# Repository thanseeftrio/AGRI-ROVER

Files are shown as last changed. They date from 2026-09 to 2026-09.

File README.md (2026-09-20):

# Agri Rover 🌾🤖 - Autonomous Agricultural Monitoring Control Center & 3D Engineering Platform

An end-to-end intelligent agricultural field rover and precision monitoring system designed for 1-acre crops (Arecanut, Orchard, and High-Clearance Row Crops).

---

## 🌟 Key Features

1. **Autonomous Crop & Plant Monitoring Dashboard**:
   - Live 1-Acre GPS Matrix Grid (150 plants tracked).
   - Real-time AI Plant Health Diagnostics (Leaf Blight, Water Stress, Frond Health).
   - Live Telemetry & Mission Control with ESP32/RPi bridge interface.
   - Farm Summary Reports and Agro-Advisory Action Plans.

2. **Interactive 3D WebGL Rover Visualizer**:
   - High-Clearance Strut Architecture with top-docked drone.
   - Real-time kinematics: Ground clearance slider (250mm - 550mm), Exploded view (0 - 100%).
   - Autonomous mission demos: Drone flight simulation, motorized soil penetration probe, foliage vision turret sweep.

3. **Production 2D Engineering Drawings & CAD Package**:
   - 4-Sheet Printable AutoCAD Vector Drawings (Front GA, Top Plan, Side Elevation, 3D Isometric).
   - Downloadable DXF manufacturing files and Judges PDF Packages.

---

## 🚀 Live Demo & Deployment

This project is configured for **Vercel**:

- **Web Dashboard**: Main Application (`/`)
- **3D Interactive Rover**: `/agribot_3d_viewer.html` or `/3d`
- **4-Sheet Engineering Drawings**: `/agribot_print_drawings.html` or `/drawings`
- **AutoCAD PDF Package**: `/cad/AgriBot_AutoCAD_2D_Judges_Package.pdf`

---

## 🛠️ Local Development

### 1. Install Dependencies
```bash
npm install
cd client && npm install && cd ..
```

### 2. Run Locally (Full-Stack Dev Server)
```bash
npm run dev
```
- Frontend UI: `http://localhost:5173`
- Backend API Server: `http://localhost:3001`

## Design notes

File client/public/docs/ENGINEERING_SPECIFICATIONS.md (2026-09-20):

# Engineering Specifications & Calculations: AgriBot-X Agricultural Rover

**Project:** Autonomous AI Agricultural Plant Monitoring Rover with Integrated Drone Docking Station  
**Revision:** v1.0  
**Design Philosophy:** "GROUND + AIR + SOIL + PLANT VISION"  

---

## 1. Kinematic & Drivetrain Sizing Analysis

### 1.1 Rover Mass Budget
- Structural Chassis Frame & Bumpers: $11.5\text{ kg}$
- 4WD Wheels, Hubs, Axles & Bearings: $8.2\text{ kg}$
- 4x Planetary Geared BLDC Motors: $6.4\text{ kg}$
- 24V 30Ah LiFePO4 Battery Pack: $6.8\text{ kg}$
- Electronics Enclosure, Compute & Drivers: $3.2\text{ kg}$
- Camera Mast, Pan/Tilt Gimbal & Sensors: $2.4\text{ kg}$
- Motorized Soil Probe Mechanism: $2.1\text{ kg}$
- Drone Docking Platform & Latches: $2.8\text{ kg}$
- Surveillance Quadcopter Drone: $0.9\text{ kg}$
- Auxiliary Wiring, Fasteners & Mounting Plates: $2.2\text{ kg}$
- **Total Unloaded Robot Mass ($M_{base}$):** **$46.5\text{ kg}$**
- **Rated Agricultural Payload ($M_{payload}$):** **$15.0\text{ kg}$**
- **Maximum Gross Operating Mass ($M_{gross}$):** **$61.5\text{ kg}$** ($W = M_{gross} \times g = 61.5 \times 9.81 = 603.3\text{ N}$)

---

### 1.2 Agricultural Terrain Resistance & Tractive Force Calculations
The rover is designed to negotiate loose loam, wet clay, gravel tracks, and crop ridges with an incline of up to $\theta = 20^\circ$ (maximum slope $\theta_{max} = 25^\circ$).

#### A. Rolling Resistance Force ($F_{rr}$)
In tilled or soft agricultural soil, the rolling resistance coefficient ($C_{rr}$) for pneumatic chevron tires is approximately $0.12 - 0.18$. We design for the conservative worst case: $C_{rr} = 0.18$.
$$F_{rr} = C_{rr} \times M_{gross} \times g \times \cos(\theta) = 0.18 \times 603.3 \times \cos(20^\circ) = 0.18 \times 603.3 \times 0.9397 = 102.0\text{ N}$$

#### B. Grade Resistance Force ($F_{grade}$)
On a $20^\circ$ slope ($36.4\%$ grade):
$$F_{grade} = M_{gross} \times g \times \sin(\theta) = 603.3 \times \sin(20^\circ) = 603.3 \times 0.3420 = 206.3\text{ N}$$

#### C. Acceleration Force ($F_{accel}$)
Target acceleration to cruising speed ($v = 1.2\text{ m/s}$) in $t = 1.0\text{ s}$ ($a = 1.2\text{ m/s}^2$):
$$F_{accel} = M_{gross} \times a = 61.5 \times 1.2 = 73.8\text{ N}$$

#### D. Total Required Tractive Force (Drawbar Pull)
$$F_{total} = F_{rr} + F_{grade} + F_{accel} = 102.0\text{ N} + 206.3\text{ N} + 73.8\text{ N} = 382.1\text{ N}$$

With a $1.25$ safety margin for soil compaction and mud resistance:
$$F_{design} = 382.1 \times 1.25 = 477.6\text{ N}$$

---

### 1.3 Motor Torque & Planetary Gearbox Sizing
The drive system utilizes 4 independently driven wheels.
- Number of drive motors: $N = 4$
- Required tractive force per wheel:
  $$F_{wheel} = \frac{F_{design}}{4} = \frac{477.6\text{ N}}{4} = 119.4\text{ N}$$
- Wheel radius ($r_{wheel}$): $\frac{300\text{ mm}}{2} = 0.15\text{ m}$
- Required continuous torque per wheel axle ($T_{axle}$):
  $$T_{axle} = F_{wheel} \times r_{wheel} = 119.4\text{ N} \times 0.15\text{ m} = 17.91\text{ N}\cdot\text{m}$$

#### Motor Sizing Confirmation:
- Selected Motor: Linix/Nidec 24V BLDC Motor with integrated 1:20 Planetary Gearbox.
- Motor nominal speed: $3000\text{ RPM}$
- Gearbox reduction ratio: $i = 20:1$
- Gearbox efficiency: $\eta_{gear} = 88\%$
- Wheel axle output speed: $\frac{3000}{20} = 150\text{ RPM}$
- Maximum linear speed:
  $$v_{max} = \frac{150 \times 2\pi}{60} \times 0.15 = 15.71\text{ rad/s} \times 0.15\text{ m} = 2.36\text{ m/s}\quad (8.5\text{ km/h})$$
  *(Electronically speed-governed to $1.2 - 1.5\text{ m/s}$ during autonomous row navigation)*.
- Motor rated torque at base: $T_{motor} = 1.1\text{ N}\cdot\text{m}$
- Axle output torque available:
  $$T_{available} = T_{motor} \times i \times \eta_{gear} = 1.1 \times 20 \times 0.88 = 19.36\text{ N}\cdot\text{m} > 17.91\text{ N}\cdot\text{m}\quad \text{[PASS]}$$
- Peak stall torque per wheel: $45.0\text{ N}\cdot\text{m}$ (allows unsticking wheels in deep agricultural mud ruts).

---

## 2. Electrical Energy Budget & Battery Runtime Sizing

### 2.1 Power Consumption Breakdown

| Operating Subsystem | Voltage | Operating Current (Avg) | Power (Continuous) | Duty Cycle (%) | Effective Power (W) |
| :--- | :--- | :--- | :--- | :--- | :--- |
| **4WD Motors (Cruising)** | 24.0 V | 4.5 A (Total across 4) | 108.0 W | 65% | 70.2 W |
| **Raspberry Pi 5 (Edge AI)** | 5.0 V | 2.4 A | 12.0 W | 100% | 12.0 W |
| **Hailo-8 AI Inference (26 TOPS)**| 3.3 V | 0.8 A | 2.6 W | 70% | 1.8 W |
| **STM32F4 Motion Microcontroller** | 3.3 V | 0.15 A | 0.5 W | 100% | 0.5 W |
| **Camera Mast Pan/Tilt Gimbal** | 12.0 V | 0.6 A | 7.2 W | 40% | 2.9 W |
| **4K RGB + Depth RealSense D435i** | 5.0 V | 1.4 A | 7.0 W | 80% | 5.6 W |
| **Livox 3D Solid-State LiDAR** | 12.0 V | 1.0 A | 12.0 W | 100% | 12.0 W |
| **u-blox ZED-F9P RTK-GNSS + IMU**| 5.0 V | 0.3 A | 1.5 W | 100% | 1.5 W |
| **4G LTE / LoRaWAN Telemetry** | 5.0 V | 0.4 A | 2.0 W | 30% | 0.6 W |
| **Motorized Soil Probe Actuator** | 24.0 V | 1.5 A | 36.0 W | 15% (At Plant) | 5.4 W |
| **Sensors (Moist/pH/EC/Weather)** | 12.0 V | 0.2 A | 2.4 W | 50% | 1.2 W |
| **Cooling Blowers & Safety LEDs** | 24.0 V | 0.4 A | 9.6 W | 100% | 9.6 W |
| **Drone Fast-Charging Dock** | 24.0 V | 5.0 A (During Dock) | 120.0 W | 12% | 14.4 W |
| **TOTAL WEIGHTED AVERAGE CONSUMPTION** | — | — | — | — | **137.7 W** |

---

### 2.2 Battery Capacity & Field Endurance
- Selected Battery Pack: $24\text{V}$ (8S1P Prismatic LiFePO4 cells, nominal $25.6\text{V}$, $30.0\text{Ah}$).
- Total Pack Stored Energy:
  $$E_{total} = 25.6\text{V} \times 30.0\text{Ah} = 768.0\text{ W}\cdot\text{h}$$
- Usable Depth of Discharge (DoD) for extended 2000+ cycle life: $85\%$
  $$E_{usable} = 768.0 \times 0.85 = 652.8\text{ W}\cdot\text{h}$$
- Continuous Operating Field Autonomy ($t_{field}$):
  $$t_{field} = \frac{E_{usable}}{P_{avg}} = \frac{652.8\text{ W}\cdot\text{h}}{137.7\text{ W}} = 4.74\text{ hours}\quad (\approx 4\text{h } 45\text{m})$$

#### Field Plant Coverage Analysis:
- Target Field Density: $150\text{ plants per acre}$.
- Average inter-plant spacing: $5.2\text{ meters}$.
- Rover transit time between plants at $1.0\text{ m/s}$: $5.2\text{ seconds}$.
- Measurement stop duration (Visual scan + soil probing): $15.0\text{ seconds}$.
- Time per plant cycle: $20.2\text{ seconds}$.
- Inspection rate: $\approx 178\text{ plants per hour}$.
- In a single $4.75\text{-hour}$ battery charge, the rover monitors:
  $$N_{plants} = 178 \times 4.74 \approx 844\text{ plants}\quad (\approx 5.6\text{ acres per charge!})$$

---

## 3. Motorized Soil Probe Mechanics & Force Analysis

### 3.1 Penetration Resistance in Agricultural Soils
Soil cone penetrometer resistance in agricultural root zones typically ranges from $0.8\text{ MPa}$ to $2.0\text{ MPa}$ ($80 - 200\text{ N/cm}^2$).
- Sensor Probe Tip Cross-Sectional Area ($A_{tip}$):
  $$A_{tip} = \frac{\pi \times d_{tip}^2}{4} = \frac{\pi \times (14\text{ mm})^2}{4} = 153.94\text{ mm}^2 = 1.54\text{ cm}^2$$
- Peak Axial Insertion Force ($F_{thrust}$):
  $$F_{thrust} = 2.0\text{ MPa} \times 153.94\text{ mm}^2 = 307.9\text{ N}$$

### 3.2 Lead Screw Driving Torque Calculation
- Lead Screw: Precision T8x2 stainless steel ($d = 8\text{ mm}$, pitch $p = 2\text{ mm}$, lead $L = 2\text{ mm}$).
- Lead angle ($\lambda$):
  $$\tan(\lambda) = \frac{L}{\pi \times d_m} = \frac{2}{\pi \times 7.0} = 0.0909 \implies \lambda = 5.20^\circ$$
- Bronze nut coefficient of friction ($\mu = 0.15$, friction angle $\phi = \arctan(0.15) = 8.53^\circ$).
- Torque required to drive lead screw downward into soil:
  $$T_{drive} = \frac{F_{thrust} \times d_m}{2} \tan(\lambda + \phi) = \frac{307.9 \times 0.007}{2} \times \tan(5.20^\circ + 8.53^\circ) = 1.078 \times \tan(13.73^\circ) = 0.263\text{ N}\cdot\text{m}\quad (26.3\text{ N}\cdot\text{cm})$$
- Selected NEMA 17 Stepper Motor produces $65.0\text{ N}\cdot\text{cm}$ holding torque.
- Safety Factor:
  $$SF = \frac{65.0}{26.3} = 2.47\quad \text{[PASS]}$$
- If the probe encounters an impenetrable rock or heavy obstruction, motor current increases beyond $2.2\text{A}$, triggering instantaneous electronic stall retraction to prevent structural deflection or sensor tip damage.

---

## 4. Drone Docking Station Kinematics & Charging Interface

### 4.1 Funnel Centering Dynamics
- Platform deck size: $480 \times 480\text{ mm}$
- Autonomous RTK + Optical Flow Landing Footprint: $\pm 35\text{ mm}$ position accuracy.
- Mechanical Funnel Incline: $30^\circ$ low-friction UHMW-PE guide wedges on all 4 quadrants.
- Inward horizontal centering force produced by drone self-weight ($m_{drone} = 0.90\text{ kg}$, $W_{d} = 8.83\text{ N}$):
  $$F_{centering} = W_d \times \sin(30^\circ) \times \cos(30^\circ) = 8.83 \times 0.5 \times 0.866 = 3.82\text{ N}$$
- Friction force with UHMW-PE ($\mu = 0.12$):
  $$F_{friction} = \mu \times W_d \times \cos(30^\circ) = 0.12 \times 8.83 \times 0.866 = 0.92\text{ N}$$
- Net self-centering sliding force:
  $$F_{net} = 3.82\text{ N} - 0.92\text{ N} = 2.90\text{ N} > 0\quad \text{[100% Reliable Gravitational Self-Centering]}$$

### 4.2 Spring Contact Electrical Charging Interface
- 2x Beryllium copper gold-plated busbars ($+24\text{V}$ and $\text{GND}$) embedded with $4\text{ mm}$ spring travel.
- Contact Force per shoe: $4.5\text{ N}$ (ensures contact resistance $R_{contact} < 15\text{ m}\Omega$).
- Fast charging rate: $24\text{V} \to 16.8\text{V}$ DC-DC CC/CV algorithm at $5\text{A}$ ($84\text{W}$).
- Recharges drone $4\text{S } 2200\text{ mAh}$ flight pack in $25\text{ minutes}$ while rover continues ground operations.

---

## 5. Electrical Wiring & System Interconnect Topology

```
+---------------------------------------------------------------------------------------+
|                                24V 30Ah LiFePO4 BATTERY PACK                          |
+---------------------------------------------------------------------------------------+
                                           |
                                [100A Rotary Isolator]
                                           |
                                  [60A MIDI Fuse]
                                           |
                                  [IP67 E-Stop Pushbutton]
                                           |
                   +-----------------------+-----------------------+
                   |                                               |
         [24V Motor Bus]                                  [Solid-State Main PDB]
                   |                                               |
     +-------------+-------------+                  +--------------+---------------+
     |                           |                  |                              |
[Dual BLDC Driver 1]   [Dual BLDC Driver 2]   [24V->12V 10A Buck]            [24V->5V 10A Buck]
  (Front L & R Motors)   (Rear L & R Motors)        |                              |
     |                           |                  +---> Livox 3D LiDAR           +---> RPi 5 (8GB)
 [4x 1024 PPR Encoders]          |                  +---> Pan/Tilt Servos          +---> Hailo-8 M.2 Hat
                                 |                  +---> Weather Shield           +---> RealSense D435i
                                 |                  +---> RS485 Transceiver        +---> u-blox F9P RTK
                                 |                                                 +---> STM32F4 MCU
                                 +-------------------------------------------------+---> LoRa / 4G Modem
                                                    |
                                       [CAN-Bus 2.0B / 1 Mbps Network]
                                                    |
             +--------------------+-----------------+--------------------+
             |                    |                                      |
      [Raspberry Pi 5]    [STM32F4 Motion MCU]                [Drone Dock Controller]
       - ROS 2 Humble      - Motor PID Closed Loops            - Optical Alignment LEDs
       - YOLOv8 Crop AI    - Soil Probe Step/Dir Control       - Retention Clamps
       - GIS Waypoints     - Limit Switches & Bumpers          - Fast-Charge Relay
```

---

## 6. Autonomous Plant Identification & GIS Field Map (P001 – P150)

The field mapping engine organizes crop monitoring around centimeter-accurate RTK coordinates:

```json
{
  "plant_id": "P042",
  "crop_type": "Arecanut",
  "coordinates": {
    "latitude": 12.9715987,
    "longitude": 77.5945627,
    "altitude_m": 892.45
  },
  "row_number": 3,
  "plant_index_in_row": 14,
  "historical_records": [
    {
      "timestamp": "2026-09-16T14:30:00Z",
      "foliage_health_index": 0.88,
      "detected_issues": ["Early Leaf Blight Stage 1"],
      "soil_metrics": {
        "moisture_vwc_percent": 34.2,
        "soil_temperature_c": 24.8,
        "ph": 6.4,
        "ec_us_cm": 1240
      },
      "aerial_inspection_required": true,
      "aerial_image_url": "s3://agribot-field/P042_canopy_4k.jpg"
    }
  ]
}
```

---

## 7. Ground + Air + Soil + Plant Vision Workflow

```
[START: WAYPOINT NAVIGATION ALONG CROP ROW]
                   │
                   ▼
       [ARRIVE AT TARGET PLANT (P_xxx)]
       Centimeter RTK-GNSS + Odometry Stop
                   │
                   ▼
     [GROUND CAMERA MULTI-ANGLE SCAN]
  - 4K RGB Camera: Leaf texture, spots, discoloration
  - Stereo Depth: Canopy volume, stem diameter
  - Multispectral: 5-band NDVI chlorophyll stress
                   │
                   ▼
       [MOTORIZED SOIL MEASUREMENT]
  - Lower probe via linear guide rail (150 mm stroke)
  - Measure: Moisture (VWC%), Soil Temp, pH, EC
  - Automatic retraction & limit switch confirmation
                   │
                   ▼
       [EDGE AI REAL-TIME INFERENCE]
  Raspberry Pi 5 + Hailo-8 (YOLOv8 Plant Pathology)
                   │
         ┌─────────┴─────────┐
         ▼                   ▼
[Standard Crop Height]    [TALL CANOPY / INACCESSIBLE CROP]
(Foliage fully imaged)    (e.g., Arecanut, Coconut crown, >3m height)
         │                   │
         │                   ▼
         │         [DRONE TAKEOFF & ASCENT]
         │         - Release mechanical retention clamps
         │         - Vertical takeoff to 8-15 m canopy altitude
         │         - Autonomous 4K Gimbal Crown Inspection
         │                   │
         │                   ▼
         │         [DRONE RETURN & PRECISION LANDING]
         │         - Visual servoing to ArUco 'H' dock marker
         │         - Funnel guide mechanical self-centering
         │         - Engage retention lock & initiate 24V charge
         │                   │
         └─────────┬─────────┘
                   │
                   ▼
       [CLOUD TELEMETRY SYNCHRONIZATION]
    Log P_xxx metrics via 4G LTE-M / LoRaWAN
                   │
                   ▼
       [NAVIGATE TO NEXT PLANT: P_xxx+1]
```

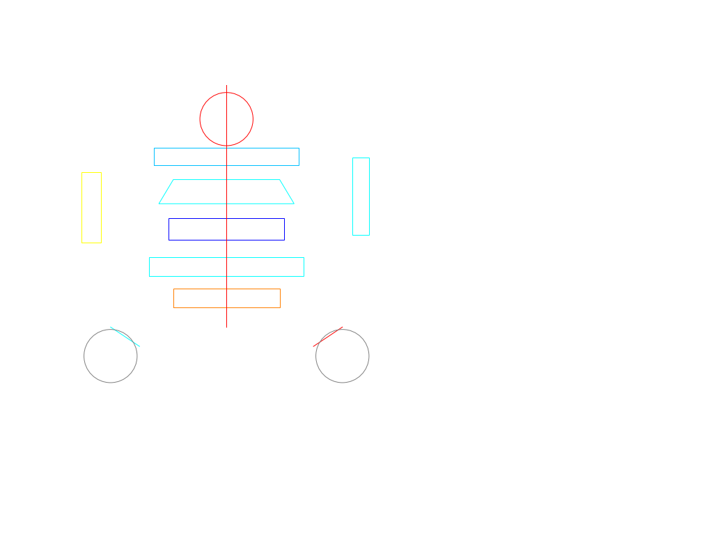
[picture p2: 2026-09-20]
client/public/cad/inspect_Sheet2.png

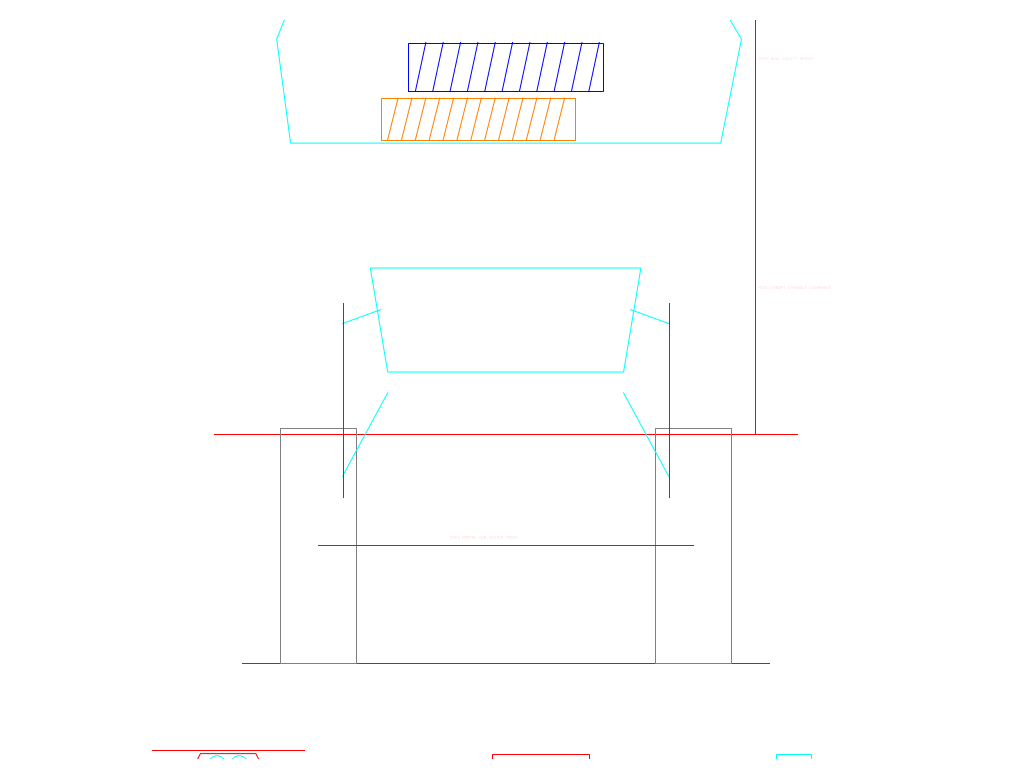
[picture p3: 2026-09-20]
client/public/cad/inspect_Sheet3.png

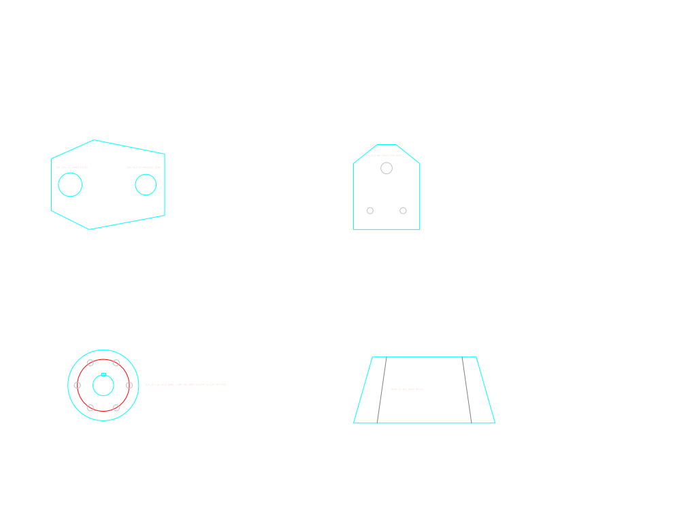
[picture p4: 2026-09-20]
client/public/cad/inspect_Sheet4.png

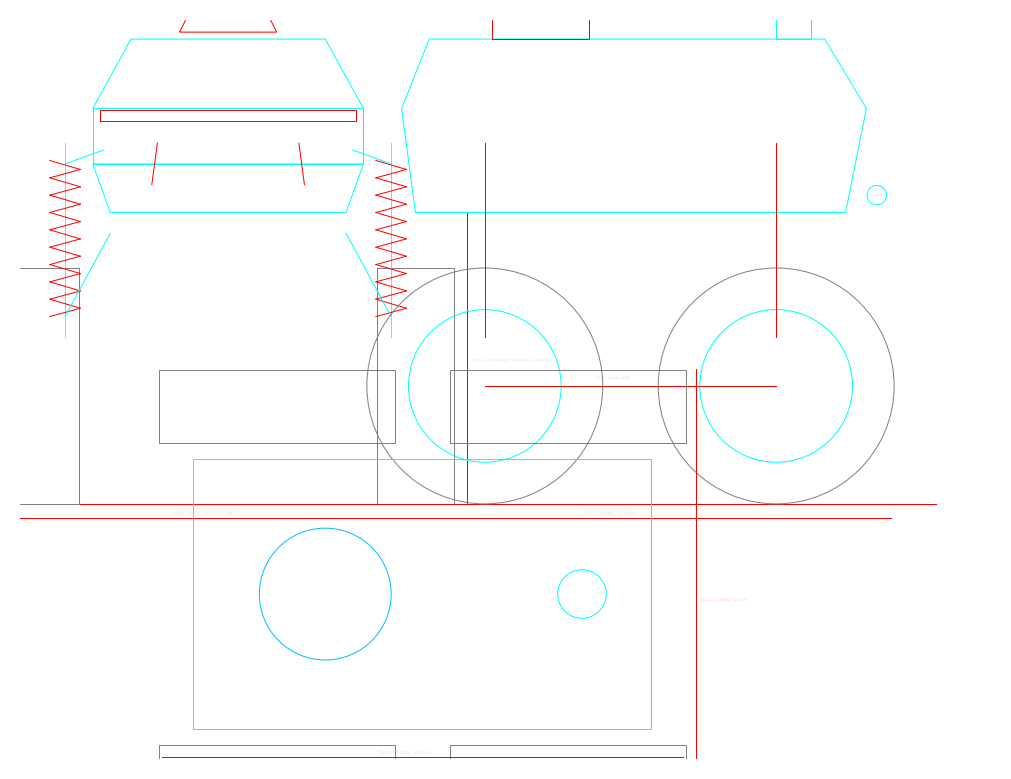
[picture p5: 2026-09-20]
client/public/cad/inspect_Sheet1.png

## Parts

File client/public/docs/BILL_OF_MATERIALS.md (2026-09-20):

# Master Bill of Materials (BOM) — AgriBot-X Agricultural Rover & Drone Dock

**Project:** Autonomous AI Agricultural Plant Monitoring Rover with Integrated Drone Docking Station  
**Revision:** v1.0 (Fabrication-Ready Prototype)  
**Standard:** ISO 2768-m / ASME Y14.5  

---

## 1. Subsystem 1: Chassis, Structural Frame & Enclosure

| Item | Component Description | Material / Manufacturing | Qty | Dimensions / Specification | COTS Supplier / Part No. | Est. Cost (USD) |
| :--- | :--- | :--- | :--- | :--- | :--- | :--- |
| **1.01** | Longitudinal Structural Rails | Al 6063-T6 Extrusion | 4 | 40x40 mm T-Slot (L=650 mm) | Misumi HFS8-4040-650 | $48.00 |
| **1.02** | Transverse Structural Crossmembers | Al 6063-T6 Extrusion | 6 | 40x40 mm T-Slot (L=280 mm) | Misumi HFS8-4040-280 | $36.00 |
| **1.03** | Vertical Corner Struts | Al 6063-T6 Extrusion | 4 | 40x40 mm T-Slot (L=270 mm) | Misumi HFS8-4040-270 | $28.00 |
| **1.04** | Corner Gusset Reinforcement Plates | Al 6061-T6 (CNC Waterjet) | 8 | 5.0 mm Thk, 90° Gusset 60x60 mm | Custom Fabrication | $32.00 |
| **1.05** | Bottom Chassis Base Plate | Al 6061-T6 (CNC Plate) | 1 | 5.0 mm x 640 mm x 360 mm | Custom Fabrication | $65.00 |
| **1.06** | Left & Right Side Protection Panels | Al 5052-H32 Sheet Metal | 2 | 2.5 mm x 560 mm x 270 mm (Louvers) | Laser Cut / Powder Coated | $45.00 |
| **1.07** | Front Bumper Assembly | Al 6061 Tubular + Rubber | 1 | Ø32 mm Tube x 420 mm W | Custom Welded / Anodized | $35.00 |
| **1.08** | Rear Bumper Assembly | Al 6061 Tubular + Rubber | 1 | Ø32 mm Tube x 420 mm W | Custom Welded / Anodized | $35.00 |
| **1.09** | Rubber Vibration Dampeners (Bumpers) | EPDM Shore 60A | 4 | M8 Stud x 30 mm OD x 25 mm H | McMaster 9376K24 | $18.00 |
| **1.10** | Wheel Mudguards / Fenders | ABS / PETG (3D Print) | 4 | 290 mm x 95 mm x 3 mm curved | FDM Printed (PA-CF / PETG) | $24.00 |

---

## 2. Subsystem 2: 4WD Rugged Drivetrain

| Item | Component Description | Material / Manufacturing | Qty | Dimensions / Specification | COTS Supplier / Part No. | Est. Cost (USD) |
| :--- | :--- | :--- | :--- | :--- | :--- | :--- |
| **2.01** | High-Torque Planetary BLDC Motors | Alloy Steel / NdFeB | 4 | 24V 350W, 1:20 Gearbox, 18 Nm | Linix / Nidec BLDC-24V-350 | $320.00 |
| **2.02** | Optical Incremental Quadrature Encoders | Polycarbonate Housing | 4 | 1024 PPR, Differential ABZ Line | Broadcom HEDS-5540#A06 | $120.00 |
| **2.03** | Machined Drive Wheel Hubs | Al 6061-T6 (CNC Lathe) | 4 | Ø120 mm Flange, 4xM10 on 100 PCD | Custom CNC Lathe Turn | $80.00 |
| **2.04** | Drive Axles & Keyways | AISI 4140 Hardened Steel | 4 | Ø20 mm g6 x 110 mm, DIN 6885-6x6 | Precision Ground / Induction | $60.00 |
| **2.05** | Deep-Groove Ball Bearings | 52100 Chrome Steel | 8 | 6005-2RS (25 mm ID x 47 mm OD) | SKF 6005-2RSH | $48.00 |
| **2.06** | Bearing Pillow Block Brackets | Al 6061-T6 (CNC Milled) | 4 | Split Clamp Housing for 47 mm OD | Custom CNC Milled | $70.00 |
| **2.07** | All-Terrain Chevron Rubber Tires | Reinforced Natural Rubber | 4 | Ø300 mm OD x 90 mm W (4.00-6) | Kenda K290 Scorpion Agri | $140.00 |
| **2.08** | Split Steel Wheel Rims | Stamped Powder-Coated Steel | 4 | 6.00" Rim Dia x 3.25" Width | COTS 6" Agri Rim | $52.00 |
| **2.09** | Motor Mounting Heavy Brackets | Al 6061-T6 (8 mm Plate) | 4 | 110 x 90 x 8 mm, Ø42 mm H7 Bore | Custom CNC Machined | $48.00 |

---

## 3. Subsystem 3: Height-Adjustable Camera Mast & Vision Sensors

| Item | Component Description | Material / Manufacturing | Qty | Dimensions / Specification | COTS Supplier / Part No. | Est. Cost (USD) |
| :--- | :--- | :--- | :--- | :--- | :--- | :--- |
| **3.01** | Vertical Structural Mast Column | Al 6063-T6 Extrusion | 1 | 40x40 mm Heavy Slot (L=400 mm) | Misumi HFS8-4040-400 | $24.00 |
| **3.02** | Mast Base Swivel / Lock Mount | Al 6061-T6 (CNC Milled) | 1 | 100 x 80 x 30 mm Clamp Base | Custom CNC Milled | $38.00 |
| **3.03** | Mast Clamping Slider & Quick Release | Al 6061-T6 + Cam Lever | 1 | Slotted Carriage with Brass Shims | Kipp K0009 Cam Clamping | $28.00 |
| **3.04** | 2-Axis Pan/Tilt Robotic Gimbal | Al 6061 & Coreless Servos | 1 | ±180° Pan, -45° to +90° Tilt (15 kg·cm) | Robotis Dynamixel / PT-20 | $185.00 |
| **3.05** | High-Resolution 4K Plant RGB Camera | Aluminum Shielded Enclosure | 1 | 12.3 MP Sony IMX477, USB 3.0 UVC | Arducam B0251 4K USB3 | $95.00 |
| **3.06** | Optical CS-Mount Low-Distortion Lens | Glass Elements / Metal Barrel | 1 | 6 mm F1.4 1/2.3" Wide Angle IR-Cut | Arducam M23060M14 | $32.00 |
| **3.07** | Stereo Depth Obstacle & Canopy Camera | Molded Body / Optical Filters | 1 | Intel RealSense D435i (RGB-D + IMU) | Intel RealSense 82635DS935 | $349.00 |
| **3.08** | Multispectral Agricultural Sensor Module | Multi-Filter Silicon Photodiode | 1 | 5 Spectral Bands (Blue, Green, Red, RedEdge, NIR) | AMS AS7341 / SparkFun | $65.00 |
| **3.09** | Weatherproof Camera Shroud Hood | Carbon-PETG 3D Printed | 1 | IP66 Gasketed Shroud with Glass Window | Additive Manufactured | $22.00 |
| **3.10** | Flexible Cable Drag Chain Guide | Reinforced Polyamide (Nylon) | 1 | 10x15 mm Interior, R18 Bend (L=500 mm) | Igus 045.10.018.0 | $16.00 |

---

## 4. Subsystem 4: Motorized Retractable Soil Probe

| Item | Component Description | Material / Manufacturing | Qty | Dimensions / Specification | COTS Supplier / Part No. | Est. Cost (USD) |
| :--- | :--- | :--- | :--- | :--- | :--- | :--- |
| **4.01** | Precision Linear Guide Rail & Block | Alloy Steel (Hardened) | 1 | MGN15H Heavy Carriage (L=250 mm) | Hiwin MGN15H-C-R250 | $42.00 |
| **4.02** | Lead Screw & Anti-Backlash Brass Nut | SS 304 & Phosphor Bronze | 1 | T8x2 (Pitch 2mm, Lead 2mm, L=260 mm) | Misumi MTS8-260 | $18.00 |
| **4.03** | Linear Actuator / Stepper Drive Motor | Alloy Housing / Neodymium | 1 | NEMA 17 Stepper (High-Torque 65 N·cm) | StepperOnline 17HS19-2004S1 | $22.00 |
| **4.04** | Flexible Jaw Shaft Coupling | Al 7075 + Polyurethane Spider | 1 | 5 mm to 8 mm Bore (OD 20 x L 25 mm) | Ruland Oldham Coupling | $14.00 |
| **4.05** | Probe Slide Carriage Mounting Plate | Al 6061-T6 (CNC Plate) | 1 | 80 x 60 x 8 mm, M3 & M4 Hole Pattern | Custom CNC Milled | $26.00 |
| **4.06** | Quick-Release Knurled Probe Chuck | Stainless Steel 303 (Knurled) | 1 | ER11 / Custom Twist-Collet (Ø12 mm) | Custom Lathe Turned | $28.00 |
| **4.07** | Soil Penetration Probe Shaft | Stainless Steel 316 (Hollow) | 1 | Ø12 mm OD x Ø8 mm ID x 160 mm L | Sandvik SS 316 Seamless | $18.00 |
| **4.08** | Multi-Parameter Soil Sensor Cartridge | SS 316 Pins / Potted Epoxy | 1 | Moisture (FDR), Temp, EC, pH (RS485) | Renke Soil 4-in-1 Sensor | $110.00 |
| **4.09** | Sub-Miniature Mechanical Limit Switches | Thermoplastic / Silver Contacts | 2 | IP67 Roller Lever Microswitch | Omron D2HW-A201D | $12.00 |
| **4.10** | Downward Surface Proximity ToF Sensor | Optical Laser Package (Class 1) | 1 | VL53L1X Time-of-Flight (4 m range) | STMicroelectronics VL53L1X | $15.00 |

---

## 5. Subsystem 5: Drone Docking Station & Surveillance Quadcopter

| Item | Component Description | Material / Manufacturing | Qty | Dimensions / Specification | COTS Supplier / Part No. | Est. Cost (USD) |
| :--- | :--- | :--- | :--- | :--- | :--- | :--- |
| **5.01** | Landing Deck Base Plate | Al 6061-T6 / Carbon Sandwich | 1 | 480 mm x 480 mm x 5 mm (Drainage Slots) | Laser Cut & Anodized | $75.00 |
| **5.02** | Beveled Auto-Centering Funnel Guides | Ultra-High-Molecular-Weight PE | 4 | 30° Incline Bevel Ramp (UHMW-PE) | CNC Milled UHMW-PE | $45.00 |
| **5.03** | Fast-Charging Contact Busbars (+24V/GND) | Beryllium Copper (Gold Plated) | 2 | 360 mm x 15 mm x 3 mm (Spring Backed) | Custom Stamped / Gold Plated | $38.00 |
| **5.04** | Active Mechanical Retention Latches | Al 6061 Hooks & Micro-Servos | 2 | Metal Gear Micro-Servo + Over-Center Cam | Savox SH-0255MG | $44.00 |
| **5.05** | High-Visibility RGB-LED Boundary Strip | Silicone Encapsulated (IP68) | 1 | WS2812B Addressable LED (L=1.9 m) | BTF-Lighting IP68 WS2812B | $22.00 |
| **5.06** | Autonomous Surveillance Drone Frame | 3K Twill Carbon Fiber Plate/Tube | 1 | 280 mm True-X Geometry (4 mm Arms) | Custom Agri-Quad Carbon | $65.00 |
| **5.07** | Drone Brushless Outrunner Motors | Steel Shaft / Neodymium | 4 | 2205 2300KV High-Efficiency Motors | Emax ECO II 2205 | $60.00 |
| **5.08** | Carbon-Reinforced Propellers | Polycarbonate / Carbon Fiber | 2 Sets | 6040 2-Blade Bullnose Props | HQProp 6x4x2 | $12.00 |
| **5.09** | Drone Autopilot Flight Controller | 32-Bit ARM Cortex-M7 | 1 | Pixhawk 6C Mini + Dual IMU + Baro | Holybro Pixhawk 6C Mini | $195.00 |
| **5.10** | Drone Miniature 4K Gimbal Camera | 2-Axis Brushless Gimbal | 1 | 4K 60FPS Video, Sony Sensor (Crown Scan) | RunCam Split 4K + Gimbal | $135.00 |
| **5.11** | Drone Landing Skids with Contact Shoes | Brass Shoes + Carbon Stems | 2 | 160 mm Long, Spring-Loaded Pins | Custom Fabricated | $24.00 |
| **5.12** | Drone Fast-Charging LiPo Battery Pack | Lithium Polymer (4S 2200 mAh) | 2 | 14.8V 2200 mAh 75C (Quick-Charge 5C) | Tattu R-Line 4S 2200 | $68.00 |

---

## 6. Subsystem 6: Electronics, Power Distribution & Compute

| Item | Component Description | Material / Manufacturing | Qty | Dimensions / Specification | COTS Supplier / Part No. | Est. Cost (USD) |
| :--- | :--- | :--- | :--- | :--- | :--- | :--- |
| **6.01** | Sealed Electronics Enclosure Housing | Die-Cast Al 380 (Gasketed) | 1 | 280 x 260 x 140 mm, IP65 Rated | Bud Industries AN-2808-A | $85.00 |
| **6.02** | Transparent Service Access Cover | Optical Polycarbonate (4 mm) | 1 | 290 x 270 x 4 mm with Neoprene O-Ring | Custom Laser Cut | $22.00 |
| **6.03** | Primary AI Edge Computer | SBC (BCM2712 2.4 GHz) | 1 | Raspberry Pi 5 (8GB RAM) + Active Cooler | Raspberry Pi 5-8GB | $80.00 |
| **6.04** | AI Neural Accelerator M.2 HAT | Hailo-8 M.2 Module (PCIe Gen3) | 1 | 26 TOPS Neural Inference (YOLOv8 Engine) | Hailo-8 M.2 + Pi5 HAT | $99.00 |
| **6.05** | Real-Time Motion Controller MCU | 32-Bit ARM Cortex-M4 Board | 1 | STM32F407VET6 Black Board (168 MHz) | STMicroelectronics | $18.00 |
| **6.06** | Dual-Channel Smart BLDC Motor Drivers | Aluminum Substrate MOSFETs | 2 | 24V 30A Continuous, CAN-Bus Protocol | ODrive Micro / Roboteq SDC | $190.00 |
| **6.07** | Industrial Power Distribution Board | 4-Layer 2oz Copper FR4 | 1 | 24V Bus, Solid-State Relays, 100A Shunt | Custom Engineered PDB | $45.00 |
| **6.08** | DC-DC Synchronous Step-Down Buck | Sealed Aluminum Brick | 2 | 24V to 12V 10A (120W) & 24V to 5V 10A (50W) | Mean Well RSD-100 / Pololu | $48.00 |
| **6.09** | Dual-Band RTK-GNSS High-Precision Unit | Multi-Constellation Receiver | 1 | u-blox ZED-F9P (GPS/GLONASS/Galileo/BDS) | SparkFun GPS-RTK2 (F9P) | $220.00 |
| **6.10** | High-Gain Multi-Band Helical Antenna | UV-Resistant Radome | 1 | L1/L2/L5 GPS/GLONASS/BeiDou/Galileo | u-blox ANN-MB-00 | $65.00 |
| **6.11** | 4G LTE-M / LoRaWAN Telemetry Modem | Quectel EC25 + SX1262 LoRa | 1 | Long-Range IoT Telemetry (868/915 MHz) | Waveshare 4G/LoRa HAT | $55.00 |
| **6.12** | Environmental Weather Station Shield | Aspirated Multi-Plate Louver | 1 | Sensirion SHT35 (Temp/RH) + BMP390 (Baro) | Custom Aspirated Radiation | $38.00 |
| **6.13** | Solid-State Front 3D Collision LiDAR | Semi-Solid State MEMS | 1 | 70° x 30° FOV, 0.1 - 25 m, 10 Hz | Livox Mid-360 / Benewake | $350.00 |
| **6.14** | Sealed Cable Glands (M12 / M16 / M20) | Nickel-Plated Brass (IP68) | 8 | Rubber Compression Bushing | Lapp Skintop MS-M | $28.00 |
| **6.15** | Forced-Air Cooling Labyrinth Blowers | Dual Ball Bearing (IP54) | 2 | 60x60x25 mm 24V PWM Fans with Dust Filter | Delta Electronics PFB0624 | $32.00 |

---

## 7. Subsystem 7: Low-CG Battery & Safety System

| Item | Component Description | Material / Manufacturing | Qty | Dimensions / Specification | COTS Supplier / Part No. | Est. Cost (USD) |
| :--- | :--- | :--- | :--- | :--- | :--- | :--- |
| **7.01** | Sliding Battery Tray Chassis Drawer | Al 5052-H32 (CNC Sheet) | 1 | 290 x 260 x 25 mm with Slam Latch | Custom Laser / Bending | $38.00 |
| **7.02** | Heavy-Duty Stainless Drawer Slides | SS 304 Full Extension | 1 Pr | 250 mm Travel, 45 kg Load Capacity | Accuride 3832SS | $34.00 |
| **7.03** | 24V 30Ah LiFePO4 Prismatic Battery Pack | Prismatic 3.2V 30Ah (8S1P) | 1 | 24V Nominal (25.6V), 768 Wh, 1C Discharge | CALB / CATL Prismatic 8S | $240.00 |
| **7.04** | Smart Battery Management System (BMS) | CAN-Bus / Bluetooth Telemetry | 1 | 8S 60A Continuous, Active Cell Balancing | Daly Smart BMS 8S 60A | $48.00 |
| **7.05** | Master Rotary Battery Isolation Switch | Polycarbonate / Copper Blades | 1 | 100A Continuous, 300A Surge, IP67 Keyed | Blue Sea Systems 6006 | $32.00 |
| **7.06** | Heavy-Duty Emergency Stop Pushbutton | Anodized Red Knob / IP67 Body | 1 | Push-to-Lock, Turn-to-Reset (2NC Contact) | IDEC HW1E-BV4F02R | $28.00 |
| **7.07** | High-Current Main Connector | Glass-Filled Polycarbonate | 2 | Anderson Powerpole SB50 (600V 50A) | Anderson Power Products SB50 | $14.00 |
| **7.08** | Automotive High-Current MIDI Fuse | Ceramic Body / Tin-Plated Zinc | 2 | 60A Fuse + Waterproof Sealed Fuse Holder | Littlefuse MIDI 0498060 | $12.00 |

---

## 8. Standard Fasteners Schedule (All Metric A2-70 Stainless Steel)

| Item | Fastener Type | Size & Thread | Quantity | Application / Subsystem | Standard |
| :--- | :--- | :--- | :--- | :--- | :--- |
| **F.01** | Hex Socket Head Cap Screw | M3 x 8 mm | 40 | Electronics Standoffs, Microswitches, LiDAR Mounts | DIN 912 |
| **F.02** | Hex Socket Head Cap Screw | M3 x 14 mm | 24 | MGN15 Carriage & Rail Mounting | DIN 912 |
| **F.03** | Button Head Socket Screw | M4 x 10 mm | 32 | Side Panels to Extrusions, Bracket Clamps | ISO 7380 |
| **F.04** | Button Head Socket Screw | M4 x 16 mm | 20 | Motor Mount Plates to BLDC Faceplate | ISO 7380 |
| **F.05** | Hex Socket Head Cap Screw | M5 x 12 mm | 48 | Extrusion Gusset Brackets & Corner Plates | DIN 912 |
| **F.06** | Hex Socket Head Cap Screw | M5 x 20 mm | 24 | Battery Drawer Rails & Bumper Mount Brackets | DIN 912 |
| **F.07** | Hex Socket Head Cap Screw | M6 x 16 mm | 36 | Chassis Frame Tie Bolts & Mast Base Swivel | DIN 912 |
| **F.08** | Hex Head Flanged Wheel Lug Bolt | M10 x 25 mm (1.25p)| 16 | Wheel Rim to Machined Hub PCD Flange | DIN 6921 |
| **F.09** | Roll-In Spring T-Nuts for 4040 Extrusion | M5 Thread | 72 | Interior Frame Structural Connections | Misumi HNTT8-5 |
| **F.10** | Roll-In Spring T-Nuts for 4040 Extrusion | M6 Thread | 36 | High-Load Corner & Mast Connections | Misumi HNTT8-6 |
| **F.11** | Nylon Insert Lock Nuts (Nyloc) | M3 / M4 / M5 / M6 | 60 | Anti-Vibration Structural Locking | DIN 985 |
| **F.12** | Form A Flat Washers | M3 / M4 / M5 / M6 | 120 | Stress Distribution across Sheet Metal | DIN 125A |

---

## 9. Bill of Materials Summary & Cost Analysis

- **Total Mechanical & Structural Fabricated Parts:** 38 Line Items ($419.00)  
- **Total Drivetrain & Motors:** 9 Line Items ($928.00)  
- **Total Sensors, Vision & Camera Mast:** 10 Line Items ($769.00)  
- **Total Motorized Soil Probe Assembly:** 10 Line Items ($307.00)  
- **Total Drone Docking Station & Surveillance Quadcopter:** 12 Line Items ($735.00)  
- **Total Electronics, Compute & AI Acceleration:** 15 Line Items ($1,400.00)  
- **Total Battery Pack, BMS & Safety Interlocks:** 8 Line Items ($446.00)  
- **Total Fasteners & Hardware:** 12 Line Items ($85.00)  

**Estimated Total Prototype Cost:** **$5,089.00 USD**  
*(Comparable commercial agricultural autonomous scouts with RTK and drone docking range from $22,000 to $45,000 USD, representing over 75% cost savings for university mechatronics and field prototype deployment).*

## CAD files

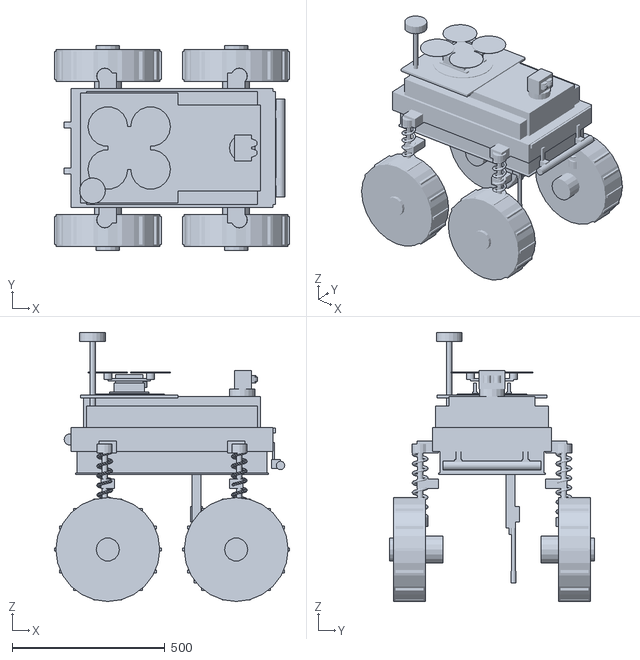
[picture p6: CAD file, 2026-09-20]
client/public/cad/agribot_3d_assembly.dxf
770.0 x 669.0 x 880.0

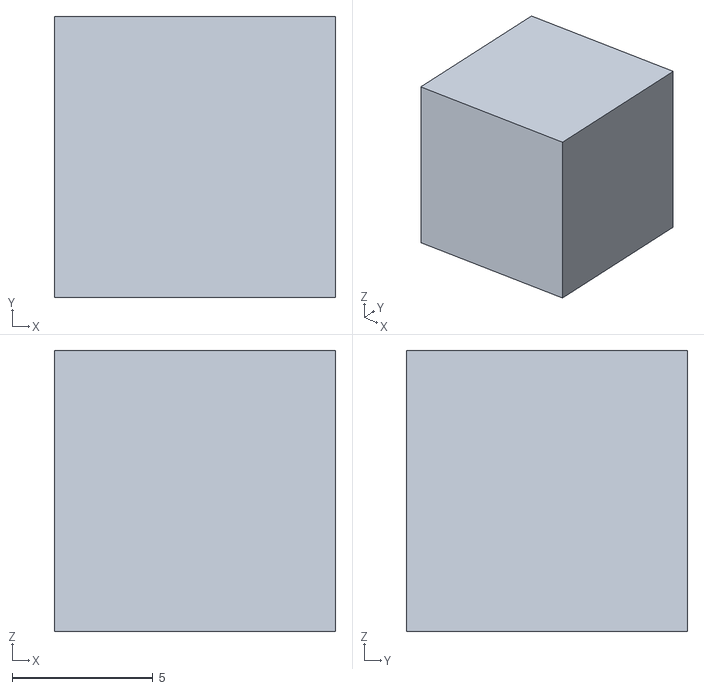
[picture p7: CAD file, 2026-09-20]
client/public/cad/test_box.dxf
10.0 x 10.0 x 10.0

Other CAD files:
client/public/cad/agribot_2d_manufacturing_package.dxf

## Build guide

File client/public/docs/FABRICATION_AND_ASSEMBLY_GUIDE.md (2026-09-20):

# Fabrication & Assembly Guide: AgriBot-X Autonomous Agricultural Rover

**Project:** Autonomous AI Agricultural Plant Monitoring Rover with Integrated Drone Docking Station  
**Revision:** v1.0  
**Target Audience:** Mechatronics Engineers, Machine Shop Technicians, Field Prototyping Teams  

---

## 1. Manufacturing & Tooling Preparation

### 1.1 Equipment Requirements
- **CNC Milling Machine / Router:** 3-Axis CNC with minimum $400 \times 300\text{ mm}$ work envelope for aluminum bracketry and hub machining.
- **CNC Waterjet / Fiber Laser:** For cutting $5.0\text{ mm}$ 6061-T6 aluminum plates and $2.5\text{ mm}$ 5052 sheet metal panels.
- **Manual / CNC Engine Lathe:** For turning Ø20 mm g6 drive axles and wheel hub flange bores with keyways.
- **Press Brake:** For bending sheet metal side covers ($90^\circ$ bends with $R=2.5\text{ mm}$ radius).
- **FDM 3D Printer:** (e.g., Bambu Lab X1C / Prusa MK4) with hardened steel nozzle for printing PA-CF (Carbon Fiber Nylon) or PETG sensor brackets and camera shrouds.
- **Metric Hand Tools:** Ball-end hex drivers (1.5, 2.0, 2.5, 3.0, 4.0, 5.0, 6.0 mm), socket wrenches, digital calipers (0-300 mm), torque wrench ($1 - 25\text{ N}\cdot\text{m}$ range).

### 1.2 Fastener Torque Specifications (A2-70 Stainless Steel)
| Fastener Thread | Target Torque ($\text{N}\cdot\text{m}$) | Target Torque ($\text{in}\cdot\text{lb}$) | Threadlocker Requirement |
| :--- | :--- | :--- | :--- |
| **M3** | $1.2\text{ N}\cdot\text{m}$ | $10.6\text{ in}\cdot\text{lb}$ | Loctite 222 (Purple - Low Strength) |
| **M4** | $2.8\text{ N}\cdot\text{m}$ | $24.8\text{ in}\cdot\text{lb}$ | Loctite 243 (Blue - Medium Strength) |
| **M5** | $5.5\text{ N}\cdot\text{m}$ | $48.7\text{ in}\cdot\text{lb}$ | Loctite 243 (Blue - Medium Strength) |
| **M6** | $9.5\text{ N}\cdot\text{m}$ | $84.1\text{ in}\cdot\text{lb}$ | Loctite 243 (Blue - Medium Strength) |
| **M8** | $23.0\text{ N}\cdot\text{m}$ | $203.5\text{ in}\cdot\text{lb}$ | Loctite 243 (Blue - Medium Strength) |
| **M10 (Lug Bolts)** | $45.0\text{ N}\cdot\text{m}$ | $398.0\text{ in}\cdot\text{lb}$ | Dry / Anti-Seize on wheel studs |

---

## 2. Step-by-Step Assembly Instructions

### Phase 1: Structural Chassis Frame Assembly
1. **Pre-load T-Nuts:** Before assembling aluminum extrusions, insert roll-in spring T-nuts into the extrusion slots according to the CAD layout:
   - Lower rails: 8x M5 T-nuts per rail for motor brackets, 4x M5 for battery drawer slides.
   - Upper rails: 6x M5 T-nuts for top docking platform mounts, 4x M6 for camera mast base.
2. **Square the Base Perimeter:** Assemble the lower 4040 rails ($650\text{ mm}$ longitudinal) and crossmembers ($280\text{ mm}$) using 8x 6061-T6 corner gussets and M5x12 socket head screws. Verify diagonal dimensions with digital calipers ($\pm 0.5\text{ mm}$ squareness tolerance).
3. **Install 5mm Base Plate:** Lay the CNC-machined 6061 base plate onto the lower frame. Fasten using counter-sunk M5 screws with blue threadlocker.
4. **Erect Vertical Corner Struts:** Mount the 4x $270\text{ mm}$ 4040 corner posts. Torqued to $5.5\text{ N}\cdot\text{m}$.
5. **Install Upper Deck Frame:** Fasten the upper $650\text{ mm}$ longitudinal rails and crossmembers to cap the rigid boxed structure.
6. **Mount Bumpers & Dampeners:** Secure the front and rear Ø32 mm tubular bumpers using the rubber isolation mounts (EPDM Shore 60A) to decouple terrain collision shocks from sensitive electronics.

---

### Phase 2: Drivetrain, Hubs & 4WD Wheels
1. **Bearing Press Fit:** Press the dual 6005-2RS sealed ball bearings into the CNC-machined bearing pillow blocks using an arbor press. Ensure bearing outer races seat fully against the internal retention shoulder.
2. **Axle & Keyway Insertion:** Slide the Ø20 mm g6 hardened stainless steel axle through the bearings. Install the DIN 6885 $6 \times 6 \times 25\text{ mm}$ drive key.
3. **Wheel Hub Installation:** Press the machined wheel hub flange over the axle and secure with an axial shaft collar or M8 end-bolt.
4. **Motor Coupling:** Align the BLDC planetary gearbox output shaft with the drive axle. Fasten the motor mounting bracket to the 4040 frame using 4x M6 bolts. Verify zero binding by spinning the hub freely by hand.
5. **Mount All-Terrain Tires:** Bolt the $300\text{ mm}$ chevron tires and 6" steel rims onto the hub studs using 4x M10 flanged lug nuts. Tighten in an alternating cross-pattern to $45\text{ N}\cdot\text{m}$.

---

### Phase 3: Motorized Retractable Soil Probe
1. **Linear Rail Mounting:** Fasten the MGN15H precision linear guide rail ($250\text{ mm}$) vertically onto the front-left chassis upright. Use dial indicator to ensure vertical runout is $< 0.05\text{ mm}$ across the $250\text{ mm}$ span.
2. **Lead Screw & Carriage:** Attach the T8x2 brass anti-backlash nut to the CNC carriage plate. Thread the lead screw through the nut and couple it to the NEMA 17 stepper motor via the flexible jaw coupling.
3. **Probe Chuck & Sensor Installation:** Thread the stainless steel quick-release knurled chuck into the carriage. Insert the multi-parameter soil sensor cartridge (Moisture, pH, EC, Temp) and hand-tighten the knurled collar.
4. **Limit Switch Calibration:** Position the upper home limit switch such that the probe tip retracts to $Z = 220\text{ mm}$ (leaving $20\text{ mm}$ safety margin above the $200\text{ mm}$ ground clearance plane). Position the lower limit switch at $Z = 50\text{ mm}$ (corresponding to $150\text{ mm}$ maximum stroke into the ground).
5. **Manual Stroke Test:** Rotate the lead screw by hand to verify smooth travel throughout the entire $150\text{ mm}$ stroke without binding.

---

### Phase 4: Height-Adjustable Camera Mast & Gimbal
1. **Vertical Rail Installation:** Bolt the $400\text{ mm}$ vertical 4040 extrusion to the front crossmember bracket ($X = +270\text{ mm}$, $Y = -160\text{ mm}$).
2. **Install Sliding Carriage:** Slide the adjustable clamping carriage onto the rail. Fasten the quick-release cam lever.
3. **Mount 2-Axis Gimbal:** Bolt the pan servo base to the carriage. Attach the tilt fork and camera housing.
4. **Camera & Sensor Integration:**
   - Mount the Sony IMX477 4K RGB camera with 6mm lens in the primary upper housing.
   - Mount the Intel RealSense D435i depth camera directly beneath the RGB camera.
   - Mount the multispectral sensor array adjacent to the RGB lens.
5. **RTK Antenna & Strobe Mast:** Screw the high-gain helical RTK antenna into the elevated mast top riser ($Z = 1060\text{ mm}$) and mount the amber autonomous strobe beacon.
6. **Cable Drag Chain:** Snap the Igus cable drag chain alongside the vertical mast, routing the USB 3.0 and power cables cleanly into the chassis interior.

---

### Phase 5: Drone Docking Station Assembly
1. **Landing Deck Mounting:** Place the $480 \times 480\text{ mm}$ carbon/aluminum deck plate atop the upper chassis rails. Fasten with 4x M6 quick-release thumb knobs.
2. **Beveled Guide Wedges:** Screw the 4x 30° UHMW-PE alignment ramps along the perimeter of the landing zone.
3. **Charging Rails:** Install the spring-loaded copper contact strips into the recessed tracks at $Y = \pm 142\text{ mm}$. Connect 14 AWG silicone wiring to the docking fast-charging relay.
4. **Retention Servos:** Mount the 2x micro-servos with locking retention cams beneath the deck. Test that the latches engage and lock the drone landing skids firmly.
5. **Perimeter LED Strip:** Adhere the IP68 RGB-LED strip around the inner perimeter of the dock and seal cable penetrations with neutral-cure RTV silicone.

---

### Phase 6: IP65 Electronics Enclosure & Battery Compartment
1. **Internal PCB Stacking:** Mount the Raspberry Pi 5 + Hailo-8 M.2 HAT, STM32F407 motion controller, and dual BLDC motor drivers onto the modular FR4 mounting baseplate using M3 nylon standoffs.
2. **Cable Gland Wiring:** Thread motor power, encoder, CAN-bus, sensor, and camera cables through the IP68 nickel-plated brass cable glands. Tighten glands until the rubber seal compresses firmly around each cable jacket.
3. **Cover Gasket Sealing:** Clean the enclosure perimeter groove. Seat the continuous neoprene O-ring gasket. Tighten the transparent polycarbonate lid screws in a criss-cross pattern to $1.2\text{ N}\cdot\text{m}$.
4. **Battery Drawer Installation:** Bolt the Accuride stainless steel drawer slides into the lower chassis cradle. Insert the battery tray with the $24\text{V } 30\text{Ah}$ LiFePO4 pack. Ensure the mechanical safety slam-latch clicks securely into place.
5. **Emergency Stop & Isolator Switch:** Mount the red E-stop button and 100A rotary disconnect switch on the rear panel.

---

## 3. Commissioning & Verification Checklist

### Pre-Power Checks
- [ ] Inspect all frame bolts with torque wrench to ensure proper fastener torque.
- [ ] Perform multimeter continuity check between rover chassis frame and battery ground (must be isolated; floating chassis ground to prevent ground loops).
- [ ] Verify that 60A MIDI main fuse is installed and all power rails ($24\text{V}, 12\text{V}, 5\text{V}, 3.3\text{V}$) are not shorted to ground.

### Initial Power-On & Firmware Bring-up
- [ ] Engage 100A rotary isolation switch. Verify power distribution LEDs illuminate.
- [ ] Confirm DC-DC converters output steady $12.0\text{V} \pm 0.1\text{V}$ and $5.1\text{V} \pm 0.05\text{V}$.
- [ ] Boot Raspberry Pi 5. Verify ROS 2 Humble node initialization and Hailo-8 neural coprocessor enumeration via `hailortcli fw-control identify`.
- [ ] Ping STM32F4 motion controller over CAN-bus at 1 Mbps. Verify motor encoder readouts match wheel rotation.
- [ ] Test Emergency Stop pushbutton: depress button and confirm motor bus power drops to 0V within $< 15\text{ ms}$.

### Subsystem Operational Testing
- [ ] **4WD Drivetrain:** Command rover forward at $0.5\text{ m/s}$ in open area. Verify straight-line tracking using odometry and RTK-GNSS.
- [ ] **Camera Mast:** Command pan $\pm 180^\circ$ and tilt $-45^\circ$ to $+90^\circ$. Verify smooth video stream from 4K Sony IMX477 and depth stream from RealSense D435i.
- [ ] **Soil Probe Cycle:** Command auto-probing sequence. Probe must lower smoothly, stop at lower limit switch, read moisture/pH/EC/temp, and retract to home position.
- [ ] **Drone Docking:** Place drone onto dock. Verify charging voltage ($16.8\text{V}$ at $5\text{A}$) across contacts. Command retention servos to lock/unlock drone skids.
- [ ] **Autonomous Navigation:** Load sample P001–P010 field map. Run autonomous waypoint following between crop rows. Verify rover stops within $\pm 2\text{ cm}$ of each plant coordinate.

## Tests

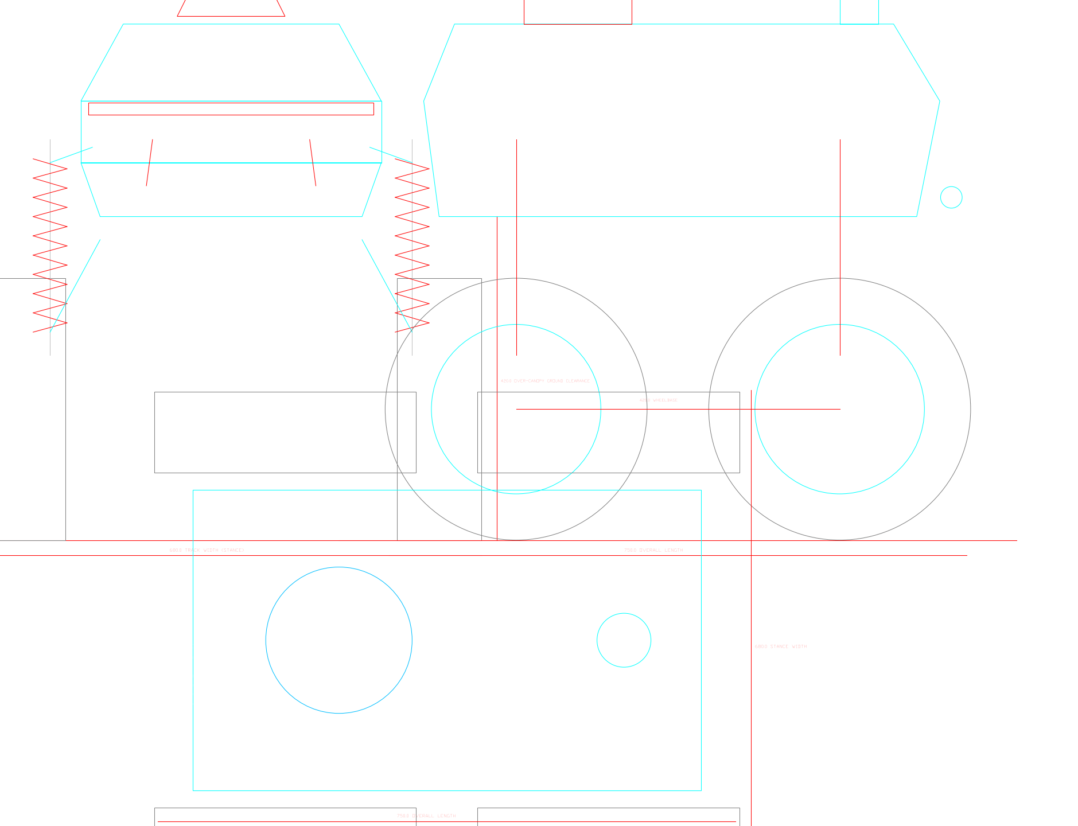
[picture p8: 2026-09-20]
client/public/cad/test_sheet1_cad.png

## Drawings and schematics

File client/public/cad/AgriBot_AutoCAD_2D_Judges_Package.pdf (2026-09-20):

DWG-01 | AGRIBOT-X SPECIFICATION - FRONT ELEVATION VIEW

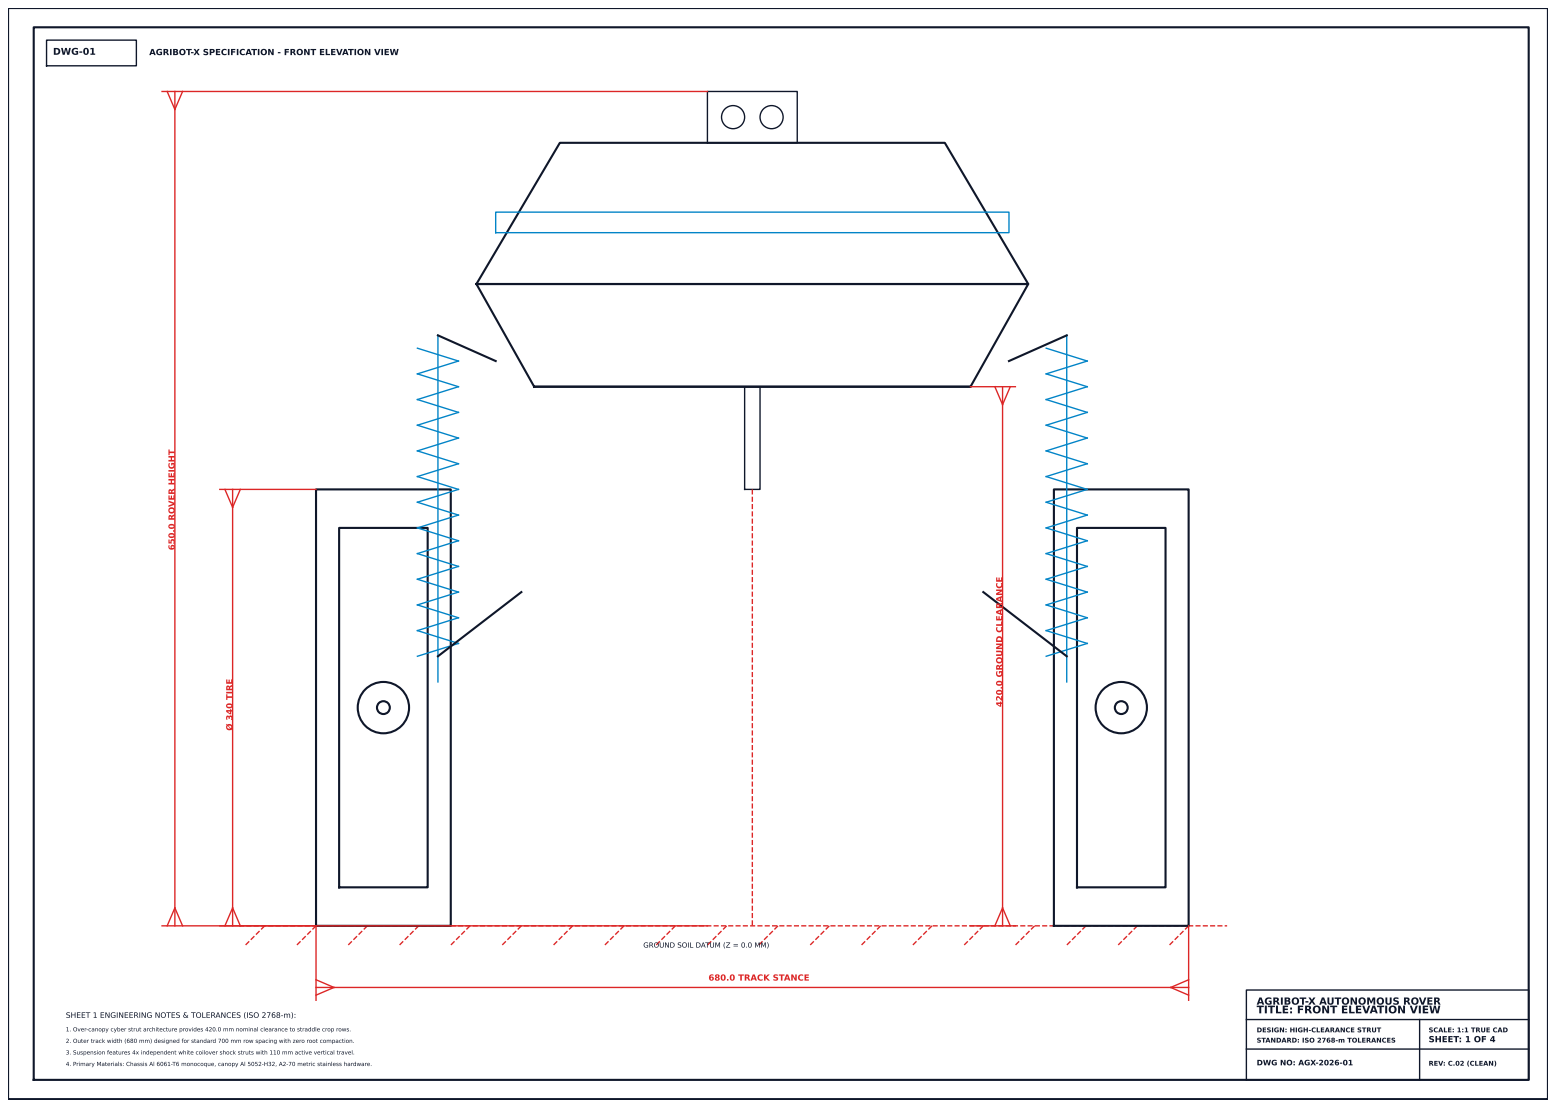
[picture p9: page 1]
DWG NO: AGX-2026-01; REV: C.02 (CLEAN); 680.0 TRACK STANCE; 420.0 GROUND CLEARANCE; 650.0 ROVER HEIGHT; Ø 340 TIRE

GROUND SOIL DATUM (Z = 0.0 MM)

AGRIBOT-X AUTONOMOUS ROVER
TITLE: FRONT ELEVATION VIEW

SHEET 1 ENGINEERING NOTES & TOLERANCES (ISO 2768-m):

1. Over-canopy cyber strut architecture provides 420.0 mm nominal clearance to straddle crop rows.

DESIGN: HIGH-CLEARANCE STRUT
STANDARD: ISO 2768-m TOLERANCES

SCALE: 1:1 TRUE CAD
SHEET: 1 OF 4

2. Outer track width (680 mm) designed for standard 700 mm row spacing with zero root compaction.

3. Suspension features 4x independent white coilover shock struts with 110 mm active vertical travel.

4. Primary Materials: Chassis Al 6061-T6 monocoque, canopy Al 5052-H32, A2-70 metric stainless hardware.

DWG-02 | AGRIBOT-X SPECIFICATION - TOP PLAN VIEW | 750.0 OVERALL LENGTH

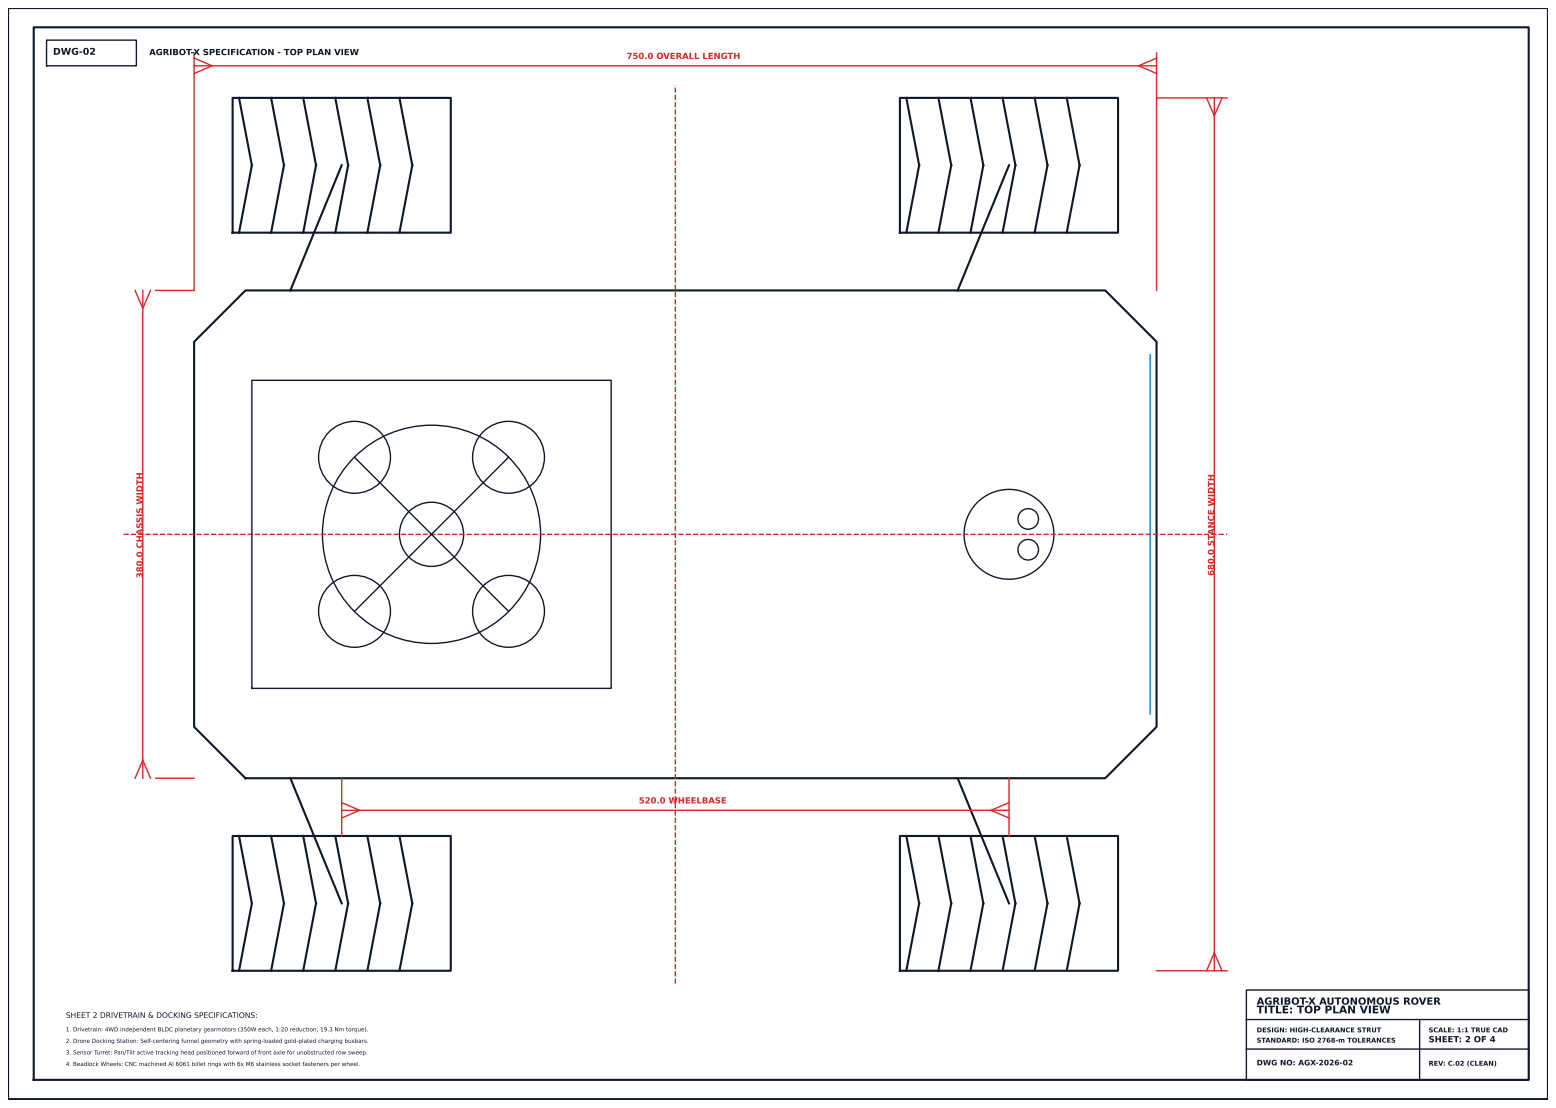
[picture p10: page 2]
DWG NO: AGX-2026-02; REV: C.02 (CLEAN); 520.0 WHEELBASE; 380.0 CHASSIS WIDTH; 680.0 STANCE WIDTH

AGRIBOT-X AUTONOMOUS ROVER
TITLE: TOP PLAN VIEW

SHEET 2 DRIVETRAIN & DOCKING SPECIFICATIONS:

1. Drivetrain: 4WD independent BLDC planetary gearmotors (350W each, 1:20 reduction, 19.3 Nm torque).

DESIGN: HIGH-CLEARANCE STRUT
STANDARD: ISO 2768-m TOLERANCES

SCALE: 1:1 TRUE CAD
SHEET: 2 OF 4

2. Drone Docking Station: Self-centering funnel geometry with spring-loaded gold-plated charging busbars.

3. Sensor Turret: Pan/Tilt active tracking head positioned forward of front axle for unobstructed row sweep.

4. Beadlock Wheels: CNC machined Al 6061 billet rings with 6x M6 stainless socket fasteners per wheel.

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

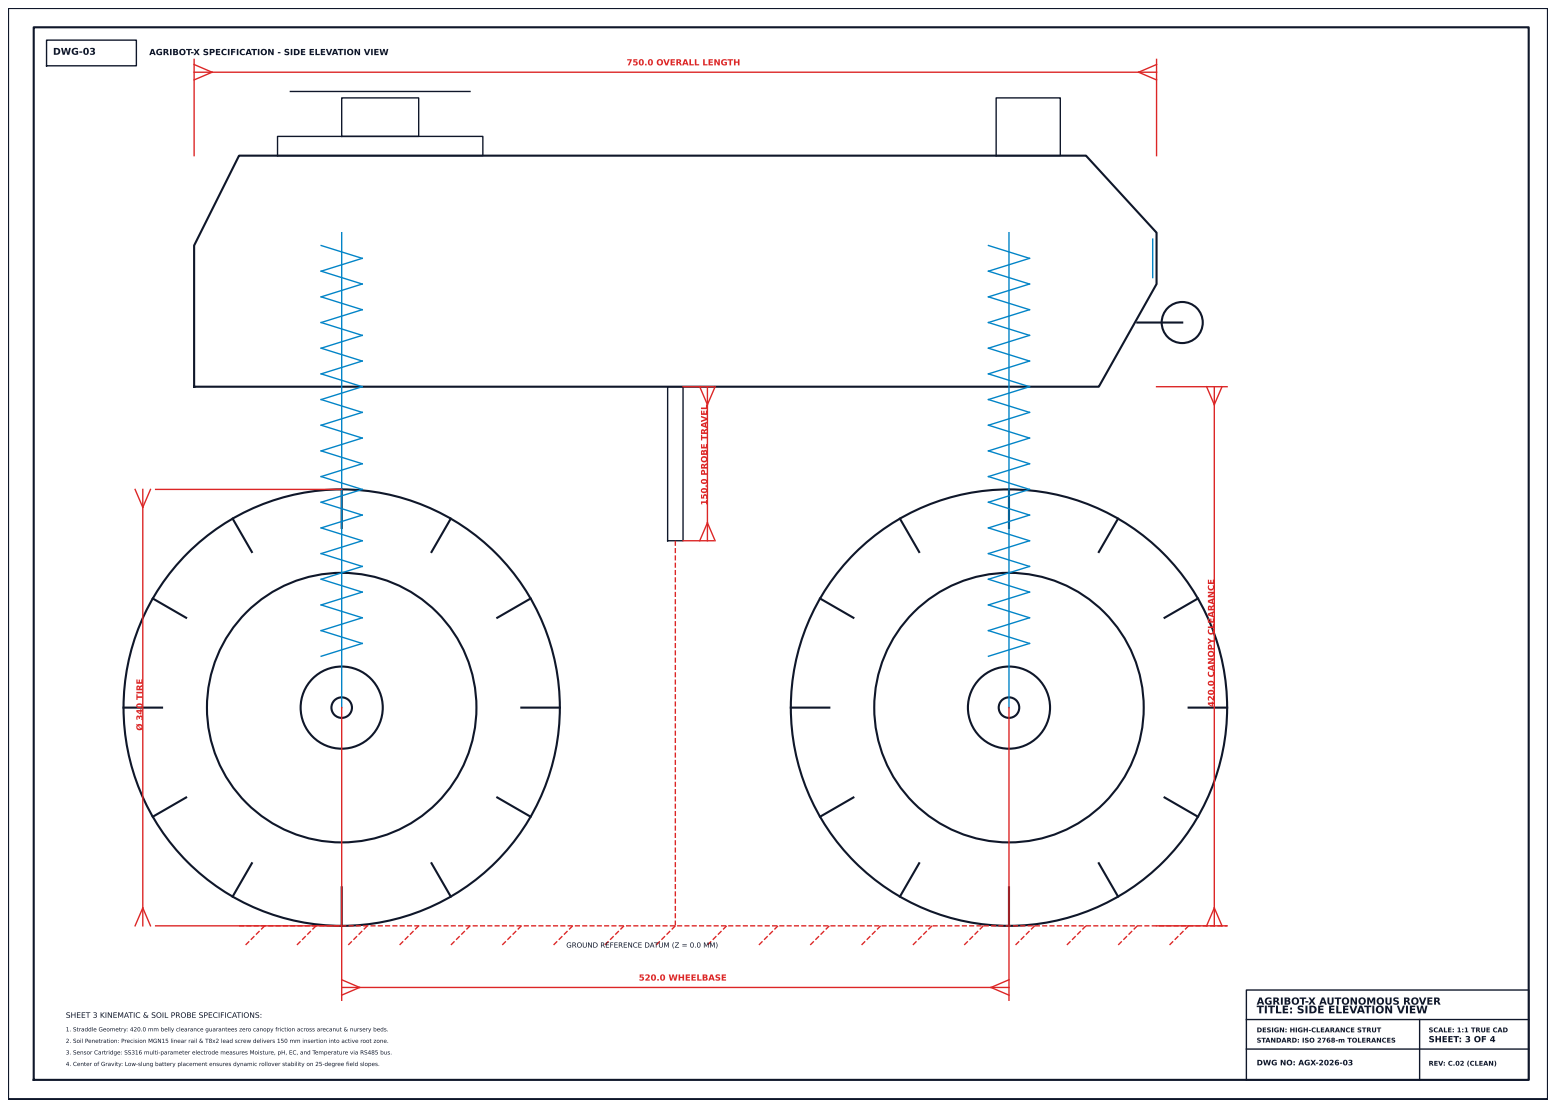
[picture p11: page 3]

DWG-04 | AGRIBOT-X SPECIFICATION - 3D ISOMETRIC ASSEMBLY

1

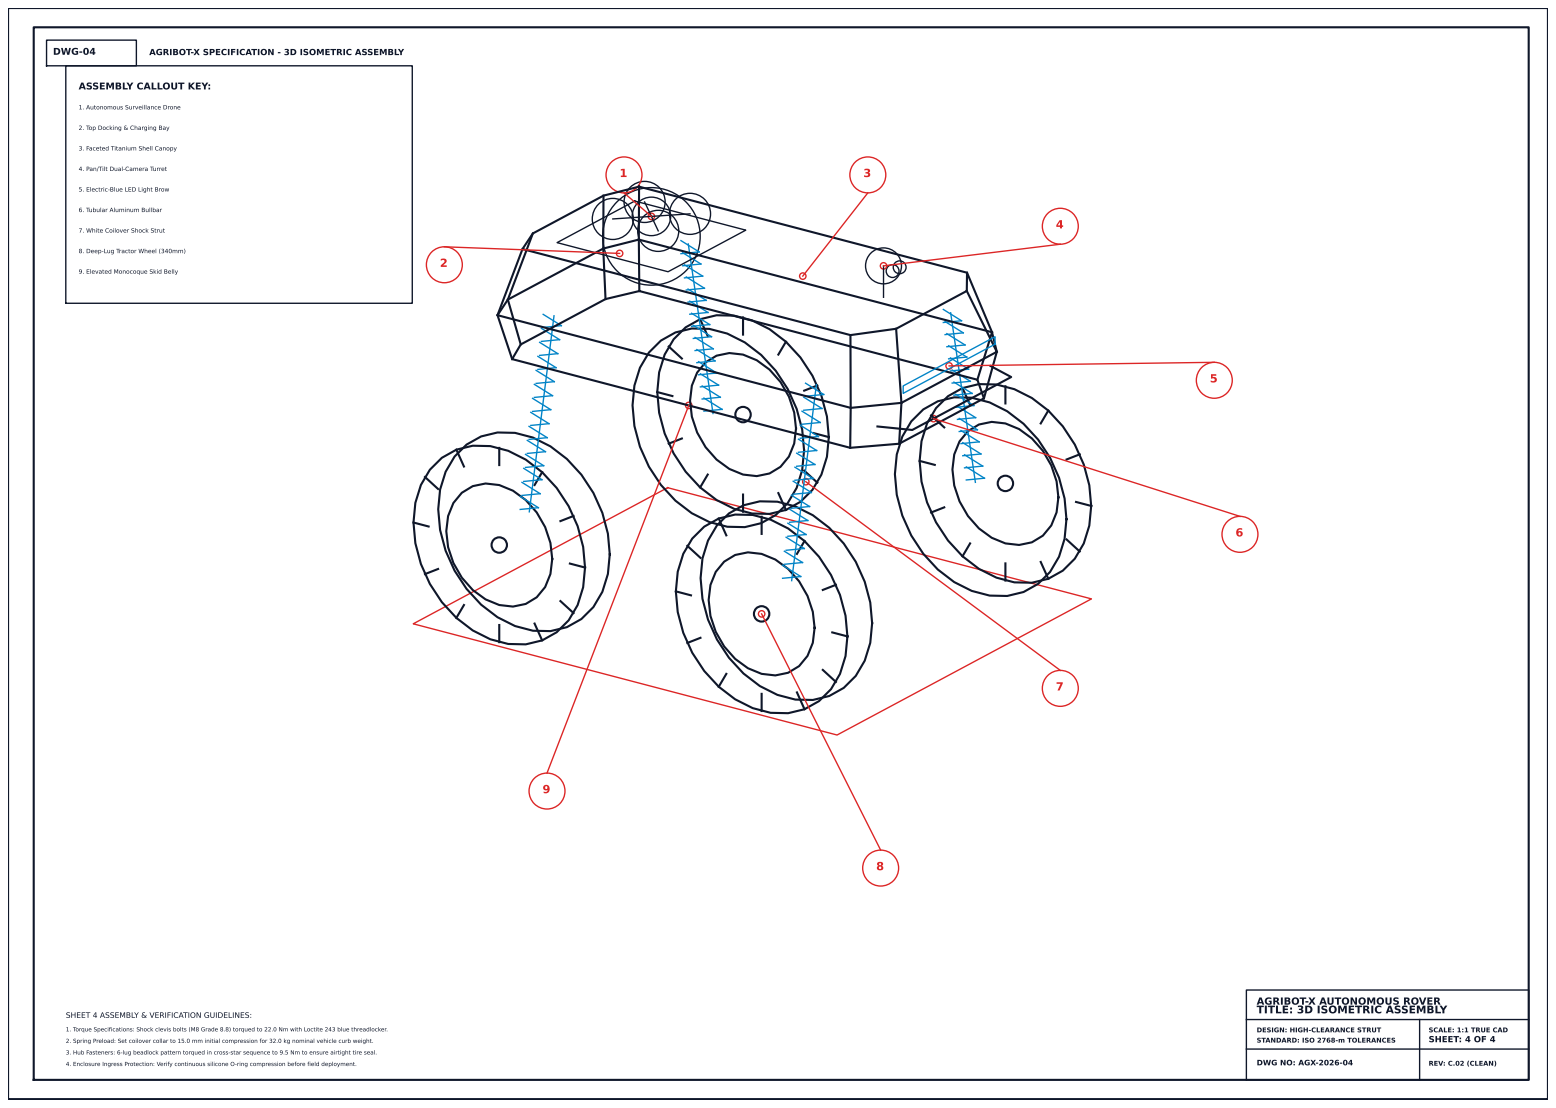
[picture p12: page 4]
DWG NO: AGX-2026-04; REV: C.02 (CLEAN)

ASSEMBLY CALLOUT KEY:

1. Autonomous Surveillance Drone

2. Top Docking & Charging Bay

3. Faceted Titanium Shell Canopy

4. Pan/Tilt Dual-Camera Turret

5. Electric-Blue LED Light Brow

6. Tubular Aluminum Bullbar

7. White Coilover Shock Strut

8. Deep-Lug Tractor Wheel (340mm)

9. Elevated Monocoque Skid Belly

AGRIBOT-X AUTONOMOUS ROVER
TITLE: 3D ISOMETRIC ASSEMBLY

SHEET 4 ASSEMBLY & VERIFICATION GUIDELINES:

1. Torque Specifications: Shock clevis bolts (M8 Grade 8.8) torqued to 22.0 Nm with Loctite 243 blue threadlocker.

DESIGN: HIGH-CLEARANCE STRUT
STANDARD: ISO 2768-m TOLERANCES

SCALE: 1:1 TRUE CAD
SHEET: 4 OF 4

2. Spring Preload: Set coilover collar to 15.0 mm initial compression for 32.0 kg nominal vehicle curb weight.

3. Hub Fasteners: 6-lug beadlock pattern torqued in cross-star sequence to 9.5 Nm to ensure airtight tire seal.

4. Enclosure Ingress Protection: Verify continuous silicone O-ring compression before field deployment.
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

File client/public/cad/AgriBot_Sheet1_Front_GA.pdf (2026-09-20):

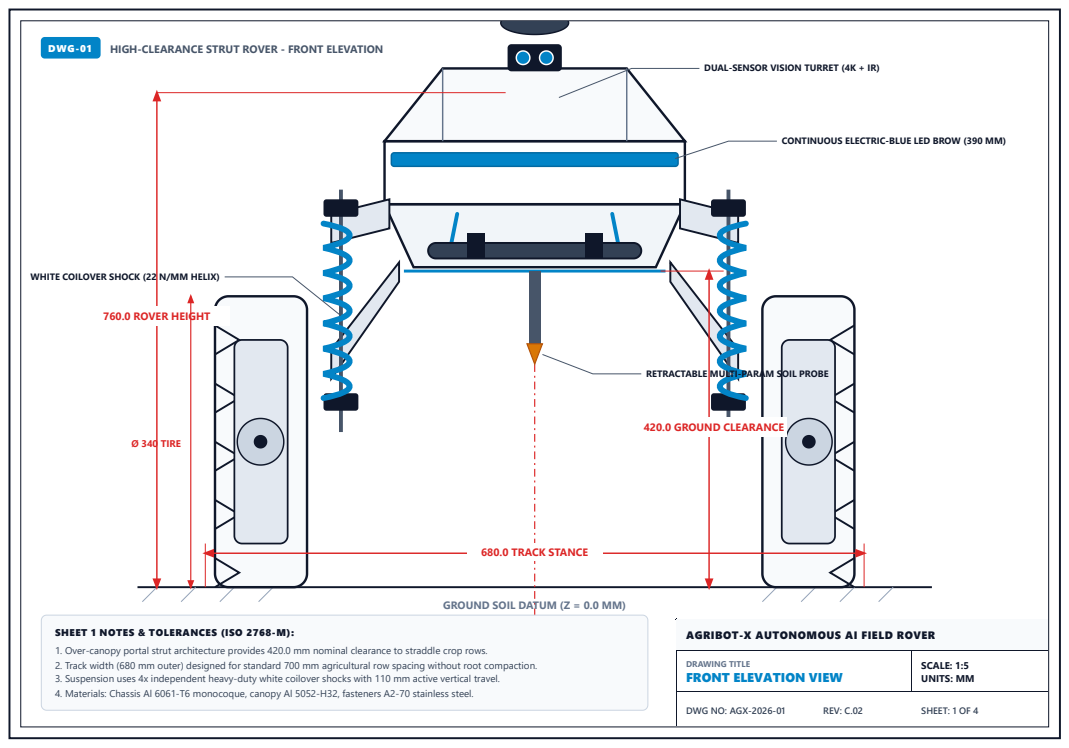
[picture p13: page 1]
680.0 TRACK STANCE; 420.0 GROUND CLEARANCE; 760.0 ROVER HEIGHT; Ø 340 TIRE; DWG-01; HIGH-CLEARANCE STRUT ROVER - FRONT ELEVATION; SCALE: 1:5 UNITS: MM; DWG NO: AGX-2026-01; REV: C.02; SHEET: 1 OF 4

DUAL-SENSOR VISION TURRET (4K + IR)

CONTINUOUS ELECTRIC-BLUE LED BROW (390 MM)

WHITE COILOVER SHOCK (22 N/MM HELIX)

RETRACTABLE MULTI-PARAM SOIL PROBE

GROUND SOIL DATUM (Z = 0.0 MM)

SHEET 1 NOTES & TOLERANCES (ISO 2768-M):
1. Over-canopy portal strut architecture provides 420.0 mm nominal clearance to straddle crop rows.
2. Track width (680 mm outer) designed for standard 700 mm agricultural row spacing without root compaction.
3. Suspension uses 4x independent heavy-duty white coilover shocks with 110 mm active vertical travel.
4. Materials: Chassis Al 6061-T6 monocoque, canopy Al 5052-H32, fasteners A2-70 stainless steel.

AGRIBOT-X AUTONOMOUS AI FIELD ROVER

DRAWING TITLE
FRONT ELEVATION VIEW

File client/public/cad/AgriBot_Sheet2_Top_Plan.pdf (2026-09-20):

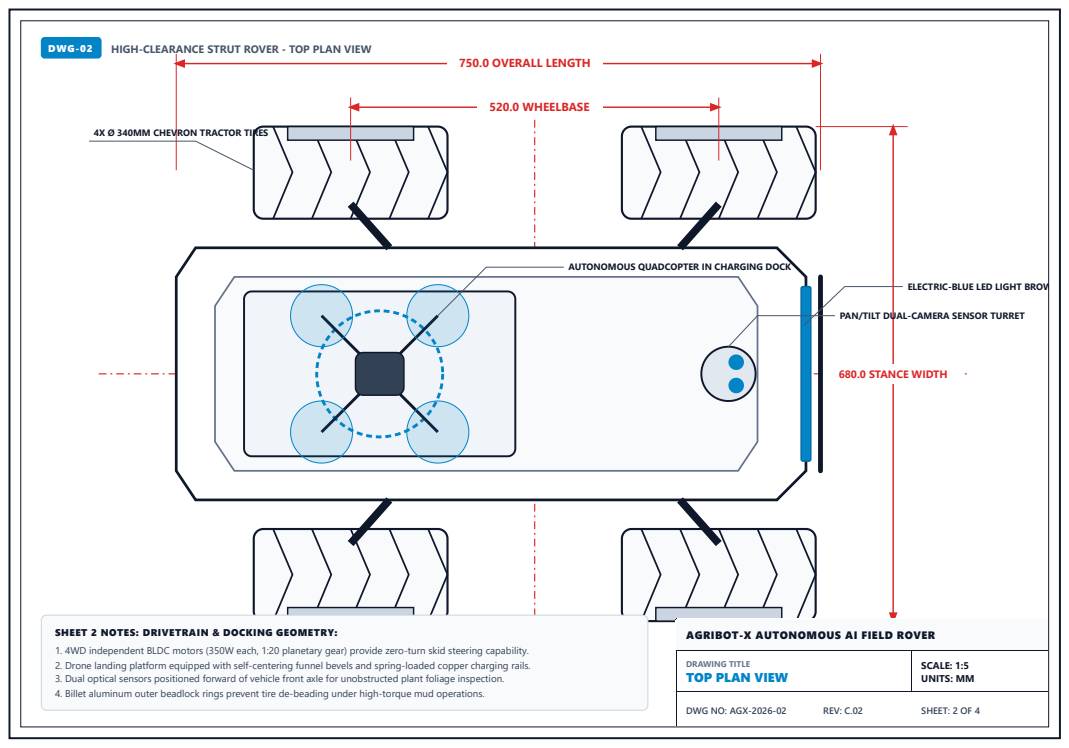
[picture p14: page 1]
750.0 OVERALL LENGTH; 520.0 WHEELBASE; 680.0 STANCE WIDTH; DWG-02; HIGH-CLEARANCE STRUT ROVER - TOP PLAN VIEW; SCALE: 1:5 UNITS: MM; DWG NO: AGX-2026-02; REV: C.02; SHEET: 2 OF 4

4X Ø 340MM CHEVRON TRACTOR TIRES

AUTONOMOUS QUADCOPTER IN CHARGING DOCK

ELECTRIC-BLUE LED LIGHT BROW

PAN/TILT DUAL-CAMERA SENSOR TURRET

SHEET 2 NOTES: DRIVETRAIN & DOCKING GEOMETRY:
1. 4WD independent BLDC motors (350W each, 1:20 planetary gear) provide zero-turn skid steering capability.
2. Drone landing platform equipped with self-centering funnel bevels and spring-loaded copper charging rails.
3. Dual optical sensors positioned forward of vehicle front axle for unobstructed plant foliage inspection.
4. Billet aluminum outer beadlock rings prevent tire de-beading under high-torque mud operations.

AGRIBOT-X AUTONOMOUS AI FIELD ROVER

DRAWING TITLE
TOP PLAN VIEW

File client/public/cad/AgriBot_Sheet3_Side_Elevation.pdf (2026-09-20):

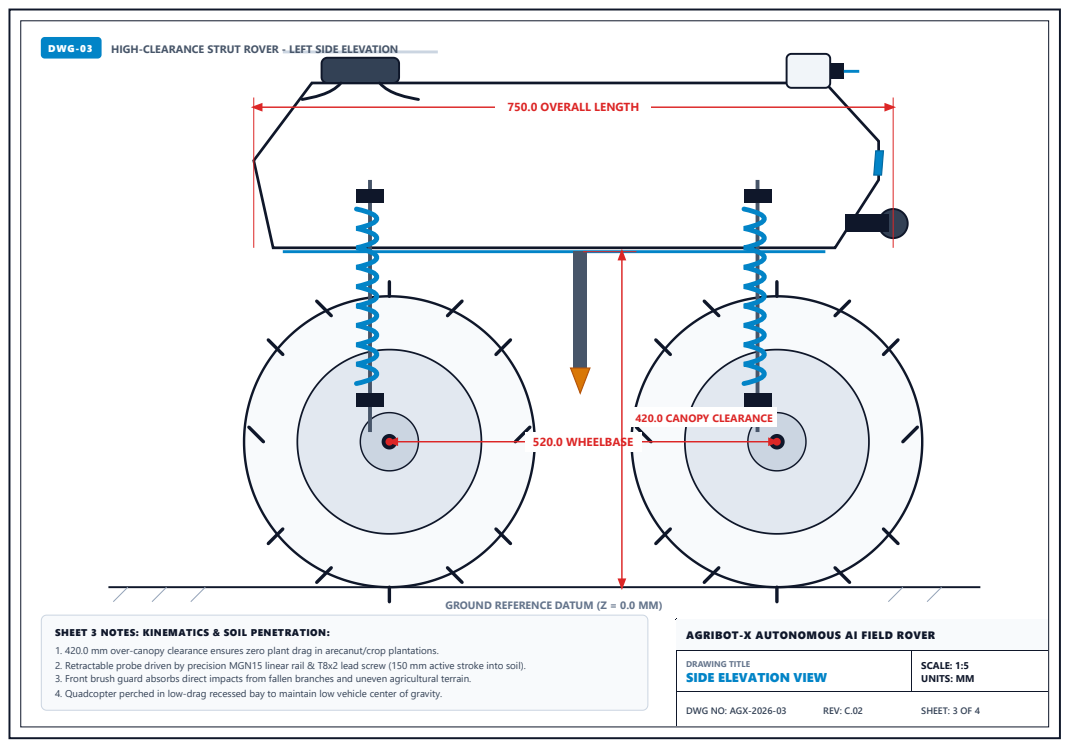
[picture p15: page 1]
750.0 OVERALL LENGTH; 520.0 WHEELBASE; 420.0 CANOPY CLEARANCE; DWG-03; HIGH-CLEARANCE STRUT ROVER - LEFT SIDE ELEVATION; SCALE: 1:5 UNITS: MM; DWG NO: AGX-2026-03; REV: C.02; SHEET: 3 OF 4

GROUND REFERENCE DATUM (Z = 0.0 MM)

SHEET 3 NOTES: KINEMATICS & SOIL PENETRATION:
1. 420.0 mm over-canopy clearance ensures zero plant drag in arecanut/crop plantations.
2. Retractable probe driven by precision MGN15 linear rail & T8x2 lead screw (150 mm active stroke into soil).
3. Front brush guard absorbs direct impacts from fallen branches and uneven agricultural terrain.
4. Quadcopter perched in low-drag recessed bay to maintain low vehicle center of gravity.

AGRIBOT-X AUTONOMOUS AI FIELD ROVER

DRAWING TITLE
SIDE ELEVATION VIEW

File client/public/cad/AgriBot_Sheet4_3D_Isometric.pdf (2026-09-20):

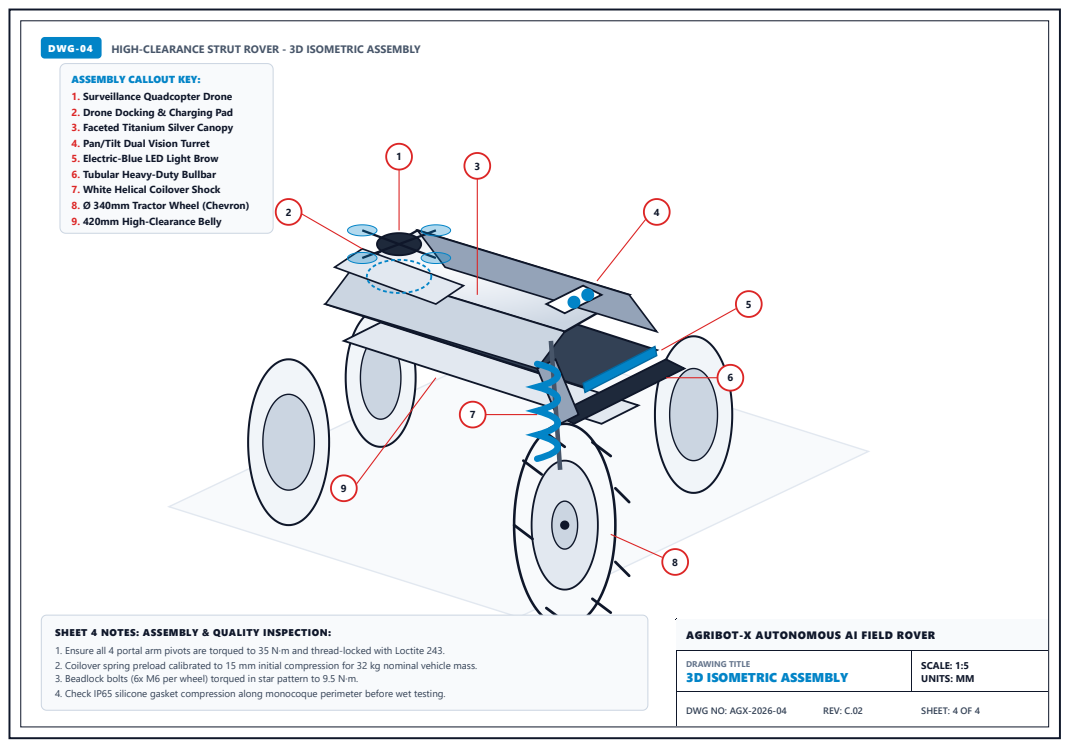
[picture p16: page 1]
DWG-04; HIGH-CLEARANCE STRUT ROVER - 3D ISOMETRIC ASSEMBLY; DRAWING TITLE 3D ISOMETRIC ASSEMBLY; SCALE: 1:5 UNITS: MM; DWG NO: AGX-2026-04; REV: C.02; SHEET: 4 OF 4

ASSEMBLY CALLOUT KEY:
1. Surveillance Quadcopter Drone
2. Drone Docking & Charging Pad
3. Faceted Titanium Silver Canopy
4. Pan/Tilt Dual Vision Turret
5. Electric-Blue LED Light Brow
6. Tubular Heavy-Duty Bullbar
7. White Helical Coilover Shock
8. Ø 340mm Tractor Wheel (Chevron)
9. 420mm High-Clearance Belly

SHEET 4 NOTES: ASSEMBLY & QUALITY INSPECTION:
1. Ensure all 4 portal arm pivots are torqued to 35 N·m and thread-locked with Loctite 243.
2. Coilover spring preload calibrated to 15 mm initial compression for 32 kg nominal vehicle mass.
3. Beadlock bolts (6x M6 per wheel) torqued in star pattern to 9.5 N·m.
4. Check IP65 silicone gasket compression along monocoque perimeter before wet testing.

AGRIBOT-X AUTONOMOUS AI FIELD ROVER

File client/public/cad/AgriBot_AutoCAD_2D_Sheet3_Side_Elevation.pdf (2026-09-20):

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
